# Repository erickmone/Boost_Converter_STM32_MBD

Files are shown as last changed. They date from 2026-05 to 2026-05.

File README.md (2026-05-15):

# Boost Converter for Model-Based Design and Embedded Control

This repository contains the hardware, simulation, modeling, and embedded-control resources developed for a **DC-DC boost converter**. The project is intended as a complete workflow for power electronics experimentation, including schematic design, PCB layout, analytical modeling, simulation, communication tests, and model-based design validation using MATLAB/Simulink.

The converter is designed as a boost-type power stage with an input voltage range from **12 V to 24 V**, a nominal output voltage of **42 V**, and a maximum output current of **5 A**. The general architecture includes the power converter, auxiliary power supply, MOSFET gate driver stage, voltage and current sensing adaptation circuits, and a microcontroller-based digital control platform operating with a PWM frequency of **500 kHz**. The block diagram included in this repository summarizes the complete system-level structure, including the power stage, sensing interface, driver, ADC acquisition, and auxiliary supply paths. :contentReference[oaicite:0]{index=0}

## Repository Structure

The repository is organized into several folders according to the main development stages of the project:

- `HW/Boost_Converter_V1.0`  
  Contains the hardware design files for the boost converter, including the PCB layout developed in **Altium Designer**.

- `INKSCAPE`  
  Includes schematic illustrations, block diagrams, and graphical material prepared using **Inkscape**. These files are useful for documentation, presentations, and technical explanations of the converter architecture.

- `MAPLE`  
  Contains symbolic calculations and additional analytical developments performed in **Maple**. These files may include derivations of converter equations, transfer functions, or supporting mathematical expressions.

- `Modbus Poll`  
  Includes material related to communication tests using **Modbus**, mainly for validating data exchange between the converter control system and external monitoring tools.

- `Papers`  
  Contains selected references and technical papers related to boost converters, digital control, power electronics modeling, and model-based design methodologies.

- `Simulation`  
  Includes simulation resources used to validate the converter operation before or alongside hardware implementation.

- `LEDtest.slxc`  
  A basic Simulink test model used to validate the embedded workflow, deployment process, and microcontroller output behavior.

- `PWM_STM32_g431xx_Boost_Converter.slx`  
  Simulink model for PWM generation on the STM32G431 platform.

- `PWM_STM32_g431xx_Boost_Converter_ADC_...slx`  
  Simulink model focused on ADC acquisition tests for voltage and current measurements.

- `PWM_STM32_g431xx_Boost_Converter_Contr...slx`  
  Simulink model including the first digital control implementation, based on a PI controller.

- `Startup_Parameters.m`  
  MATLAB script containing initialization parameters used by the Simulink models.

- `Transfer_Functions_Boost_STM32.m`  
  MATLAB script for defining and analyzing boost converter transfer functions.

- `regiones_Boost_STM32.m`  
  MATLAB script associated with the analysis of control regions or stability-related computations.

## Project Overview

The main goal of this repository is to document and validate a complete development process for a digitally controlled boost converter. The workflow combines classical power electronics design, simulation-based validation, and embedded implementation through model-based design.

The project includes:

1. **Power stage design**  
   The converter is based on a boost topology designed for low-voltage DC input and a regulated higher-voltage DC output.

2. **Hardware development**  
   The PCB layout is developed in Altium Designer and includes the main power stage, sensing circuits, auxiliary power supply, and interface connections for digital control.

3. **Graphical documentation**  
   System diagrams and converter illustrations are prepared in Inkscape to support documentation, presentations, and educational material.

4. **Analytical modeling**  
   Symbolic and numerical calculations are included to support the derivation of the dynamic model, transfer functions, and control-oriented representations.

5. **Model-based design validation**  
   Several Simulink models are included to validate the embedded workflow step by step, starting from basic LED tests, then PWM generation, ADC acquisition, and finally digital PI control.

6. **Communication testing**  
   Modbus-related files are included for communication and monitoring experiments.

7. **Experimental visualization**  
   Additional PDF diagrams and visual resources are included to document the overall architecture, signal flow, and system-level integration.

## Hardware Specifications

The preliminary system specifications are:

| Parameter | Value |
|---|---:|
| Converter topology | Boost converter |
| Input voltage range | 12 V – 24 V |
| Maximum input current | 10 A |
| Output voltage | 42 V |
| Maximum output current | 5 A |
| PWM frequency | 500 kHz |
| Control platform | STM32G431-based microcontroller |
| Control approach | Digital PI control |
| Sensing | Voltage and current ADC acquisition |
| Auxiliary supplies | 5 V and 3.3 V |

## Model-Based Design Tests

This repository includes several Simulink-based tests for embedded validation. The workflow follows a progressive strategy:

1. **LED test**  
   Basic deployment and GPIO validation on the target microcontroller.

2. **PWM generation test**  
   Validation of high-frequency PWM generation for the MOSFET gate driver.

3. **ADC acquisition test**  
   Verification of voltage and current measurement channels.

4. **Digital PI controller test**  
   First closed-loop control implementation for the boost converter.

This progressive validation approach makes it easier to isolate hardware, firmware, and control-design issues before integrating the complete system.

## Visualization and Documentation

The repository also includes visual documentation files, such as block diagrams and schematic illustrations. These resources are intended to make the project easier to understand from a system-level perspective.

The general block diagram describes the interaction between:

- DC input power supply,
- boost power stage,
- MOSFET gate driver,
- microcontroller,
- ADC sensing and adaptation circuits,
- auxiliary 5 V and 3.3 V power supplies,
- output load.

These visual elements are especially useful for tutorials, reports, presentations, and future educational material.

## Videos

A future section will include videos showing experimental tests and development progress. Possible video topics include:

- Hardware overview of the boost converter PCB.
- PWM generation test using STM32 and Simulink.
- ADC acquisition for voltage and current sensing.
- First open-loop experiments.
- Digital PI controller validation.
- Modbus-based monitoring.
- Complete system demonstration.

Video links will be added here as the tests are documented.

## Notes

Some files and scripts may include additional packages, preliminary variables, or unused sections. These elements are intentionally preserved because the repository is expected to evolve toward more advanced control-oriented tasks, including transfer-function analysis, stability-region computation, and digital controller validation.

Most of the material is currently organized as a development repository. Future updates may include a complete tutorial, additional experimental results, and a more detailed explanation of the mathematical modeling and embedded implementation.

## Author

Developed by:

- Michael Hernández & [@erickmone](https://www.github.com/erickmone)

You can also follow my academic work here:

- [Google Scholar](https://scholar.google.com/citations?hl=es&user=TdECTdoAAAAJ)

## Acknowledgments

This project is part of an ongoing effort to develop, validate, and document power electronics converters using simulation, hardware design, and model-based embedded control tools.

Special emphasis is placed on reproducible workflows for power electronics education and research, combining tools such as:

- MATLAB/Simulink,
- STM32 embedded targets,
- Altium Designer,
- Maple,
- Inkscape,
- Modbus-based communication tools.

---

NopaLabs Logo

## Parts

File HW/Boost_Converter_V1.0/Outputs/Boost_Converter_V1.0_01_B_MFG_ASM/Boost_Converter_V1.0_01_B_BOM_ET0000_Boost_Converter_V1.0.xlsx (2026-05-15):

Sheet: Part List Report
 | BILL OF MATERIAL |  |  | ET0000
 |  |  |  | Boost_Converter_V1.0
 | PCB Reference: |  |  | Boost_Converter_V1.0
 | Assembly Reference: |  | ASM number : | Boost_Converter_V1.0
 |  |  | ASM Variant : | 01
 |  |  | ASM Index (Lot) : | B
 | Report Date: |  |  | 07/11/2025 | 07:44
# | Designator | Comment | Description | Footprint | manufacturer | Part Number | Supplier 1 | Supplier Part Number 1 | Code Achat | Quantity
1 | C1 | 270pF | CAP CER 270PF 100V C0G/NP0 0603 | CAP 0603_1608 | KEMET | C0603C271J1GACAUTO |  |  |  | 1
2 | C2, C4, C5, C6, C7 | 10 µF | CAP CER 10UF 100V X7S 1210 | MURATA - GRM32E | Murata Electronics | GRM32EC72A106KE05L | DigiKey | 490-16266-1-ND |  | 5
3 | C3, C19, C20 | 100nF@100V | CAP CER 0.1UF 100V X8R 0603 | CAP 0603_1608 | Murata Electronics | GCG188R92A104KA03D | DigiKey | 490-18197-1-ND |  | 3
4 | C8, C9, C10, C11, C12, C13, C14, C15, C18, C21 | 0.1 µF | CAP CER 0.1UF 16V X7R 0603 | CAP 0603_1608 | Yageo | CS0603KRX7R7BB104 | DigiKey | 311-3560-1-ND |  | 10
5 | C16, C17, C22 | 220nF | CAP CER 0603 220NF 16V X7R 10% | CAP 0603_1608 | KEMET | C0603C224K4RECAUTO |  |  |  | 3
6 | D1 | Red | LED RED SMD | LED 0603_1608 RED | Citizen | CL-195HR-CD-T | DigiKey | 1642-1492-1-ND |  | 1
7 | D2 | White | LED WHITE SMD | LED 0603_1608 | Citizen | CL-198N-WS-D-T | DigiKey | 1642-1495-1-ND |  | 1
8 | D3 | V40PW10C-M3/I | Rectifier Diode Schottky 100V 40A 3-Pin(2+Tab) Slim DPAK T/R | TO-252 | Vishay | V40PW10C | Mouser | 78-V40PW10C-M3/I |  | 1
9 | L1 | 15µH@14A | FIXED IND 15UH 14A 9 MOHM SMD | WURTH WE-HCI 1890 | Würth Elektronik | 74435571500 |  |  |  | 1
10 | Q1 | IPD30N12S3L-31 | Mosfet Single, 30A, 120V, 57W, To-252-3 Rohs Compliant: Yes |Infineon | TO-252 | Infineon | IPD30N06S4L-23 | Mouser | 726-IPD30N12S3L31AT |  | 1
11 | R1 | 2R21 | RES 2.21 OHM 1% 1/8W 0603 | RES 0603_1608 | KOA Speer Electronics, Inc. | RK73H1JTTD2R21F |  |  |  | 1
12 | R2, R3 | 22R | RES SMD 22 OHM 1% 1/10W 0603 | RES 0603_1608 | Panasonic Electronic Components | ERJ-3EKF22R0V | DigiKey | P22.0HCT-ND |  | 2
13 | R4, R9, R10, R11, R12, R13, R14, R15, R16 | 10k | RES 10K OHM 0.1% 1/10W 0603 | RES 0603_1608 | Vishay Dale | TNPW060310K0BETA |  |  |  | 9
14 | R5 | 10R | RES SMD 10 OHM 1% 1/4W 0603 | RES 0603_1608 | Rohm Semiconductor | ESR03EZPF10R0 | DigiKey | RHM10.0ADCT-ND |  | 1
15 | R6, R7, R8 | 300K | RES SMD 300K OHM 1% 1/3W 0603 | RES 0603_1608 | Vishay Dale | CRCW0603300KFKEAHP | DigiKey | 541-CRCW0603300KFKEAHPCT-ND |  | 3
16 | Rcs1, Rcs2 | 0R01 | RES 0.01 OHM 1% 3W 2512 | RES 2512_6432 | Vishay Dale | WSLP2512R0100FEA |  |  |  | 2
17 | U1 | STM32G431KBT6 | STMICROELECTRONICS STM32G431KBT6 MCU ARM, STM32 Family STM32G4 Series Microcontrollers, ARM Cortex-M4F, 32 bits, 170 MHz, 128 KB Fabricant | STM-LQFP32_N | STM | STM32G431KBT6 | Farnell | 3132405 |  | 1
18 | U2 | IX4310T | 2 Ampere High Speed Low-Side MOSFET Driver | SOT-23-5 | IXYS | IX4310T |  |  |  | 1
19 | U3 | AP7381-50Y-13 | IC REG LINEAR 5V 150MA SOT89 | DIODES INC SOT-89 | Diodes Incorporated | AP7381-50Y-13 |  |  |  | 1
20 | U4, U6 | INA296B1IDDFR | 10V/V "-5-V TO 110-V, BIDIRECTIONAL, 1." Current Sense Amplifier 1 Circuit Single-Ended 8-VSSOP | SOT65P280X110-8N | Texas Instruments | INA296B1IDDFR | Mouser | 595-INA296B1IDDFR |  | 2
21 | U5 | AP7381-33Y-13 | IC REG LINEAR 3.3V 150MA SOT89 | DIODES INC SOT-89 | Diodes Incorporated | AP7381-33Y-13 |  |  |  | 1
 |  |  |  |  |  |  |  |  |  | 51
Approved |  |  |  |  | Notes
 |  |  |  |  | NC/DNC = Non Câblé
 |  |  |  |  | Affichage : Verifier l'alignement automatique des lignes sous peine d'occultation de certaines références
 |  |  |  |  | Codes Achat:
 |  |  |  |  |  | A = Appro sur caratéristiques
 |  |  |  |  |  | B = Référence Fabricant à respecter

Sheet: Project Information
Project Full Path | C:\Mike\Mike\Boost_Converter\Boost\HW\Boost_Converter_V1.0\Boost_Converter_V1.0.PrjPcb
Project Filename | Boost_Converter_V1.0.PrjPcb
Variant Name | 01
Data-Source Filename | Boost_Converter_V1.0.PrjPcb
Data-Source Full Path | C:\Mike\Mike\Boost_Converter\Boost\HW\Boost_Converter_V1.0\Boost_Converter_V1.0.PrjPcb
Title | ET0000
Total Quantity | 51
Report Time | 07:44
Report Date | 07/11/2025
Report Date & Tine | 07/11/2025 07:44
Output Name | Bill of Materials
Output Type | BomReport
Output Generator Name | BOM
Output Generator Description | TemplateBOM_1

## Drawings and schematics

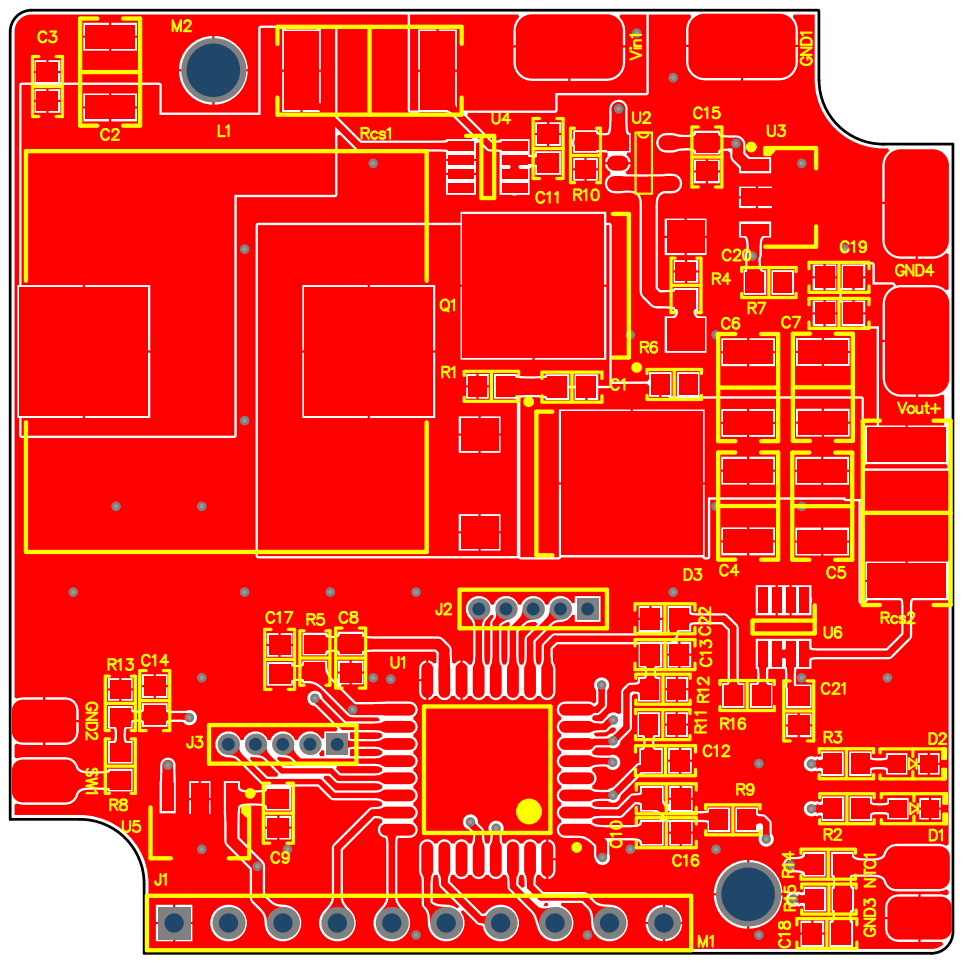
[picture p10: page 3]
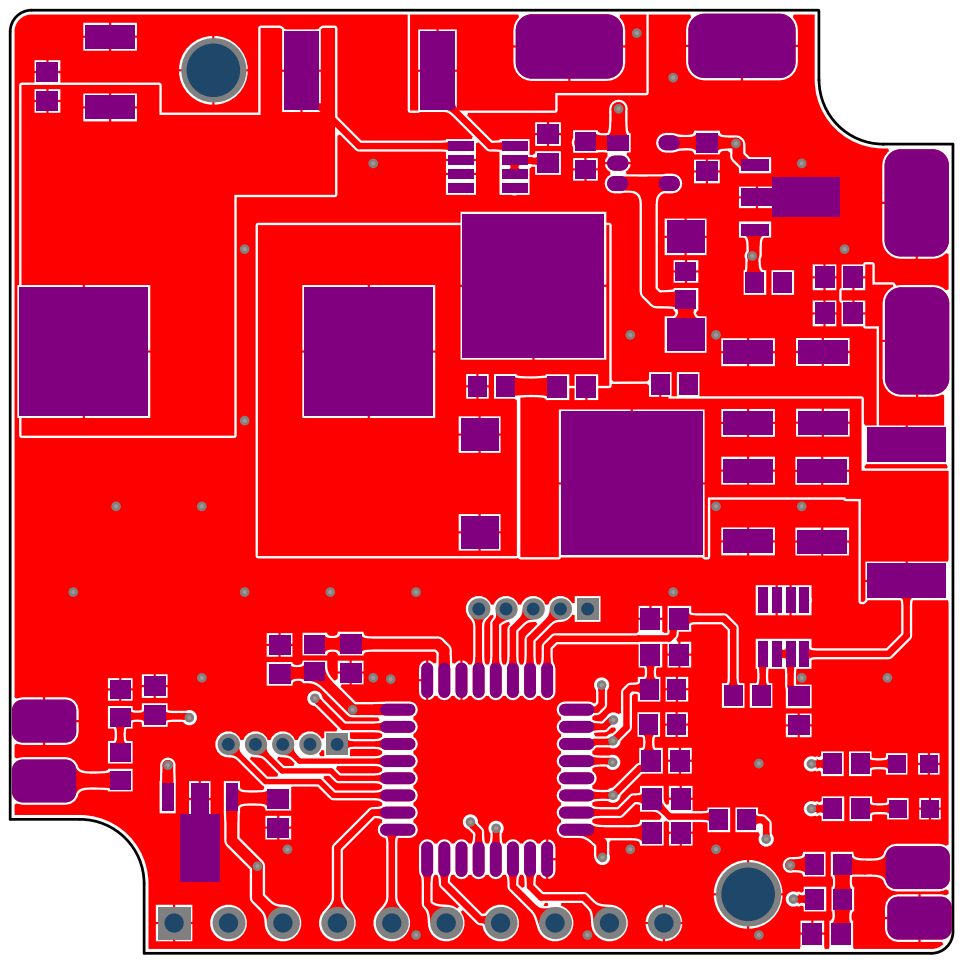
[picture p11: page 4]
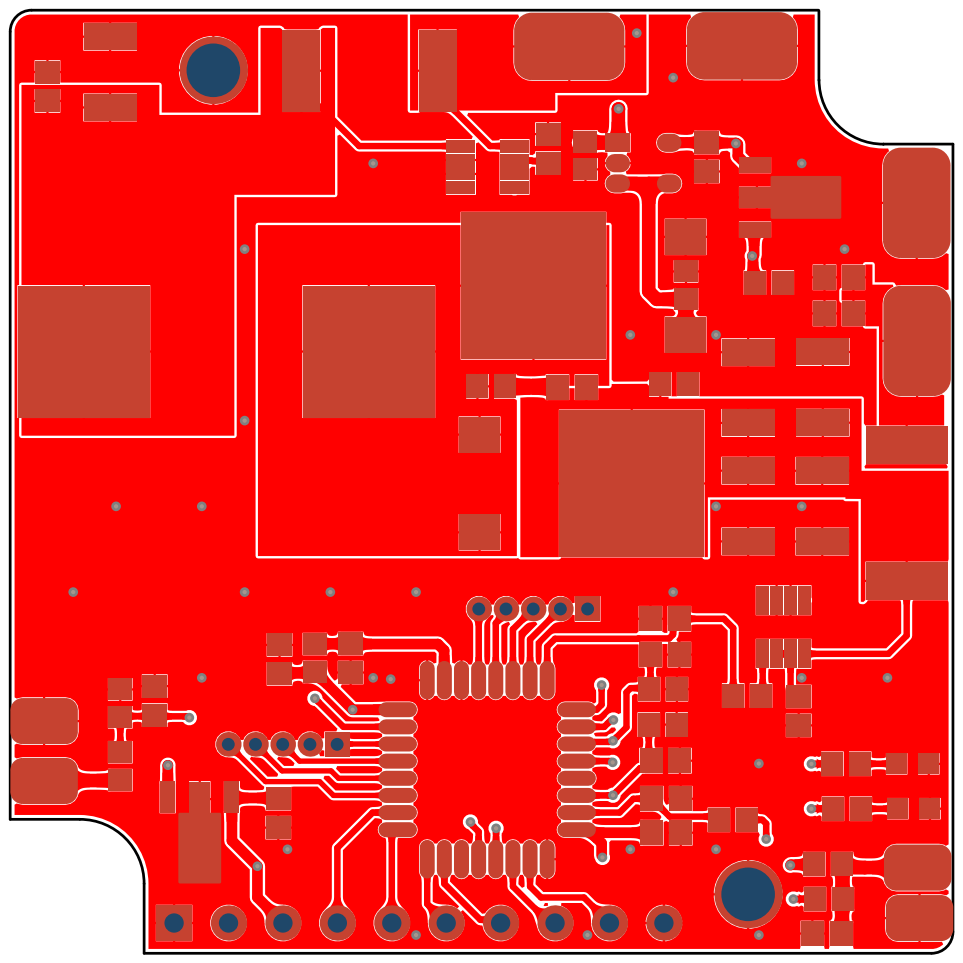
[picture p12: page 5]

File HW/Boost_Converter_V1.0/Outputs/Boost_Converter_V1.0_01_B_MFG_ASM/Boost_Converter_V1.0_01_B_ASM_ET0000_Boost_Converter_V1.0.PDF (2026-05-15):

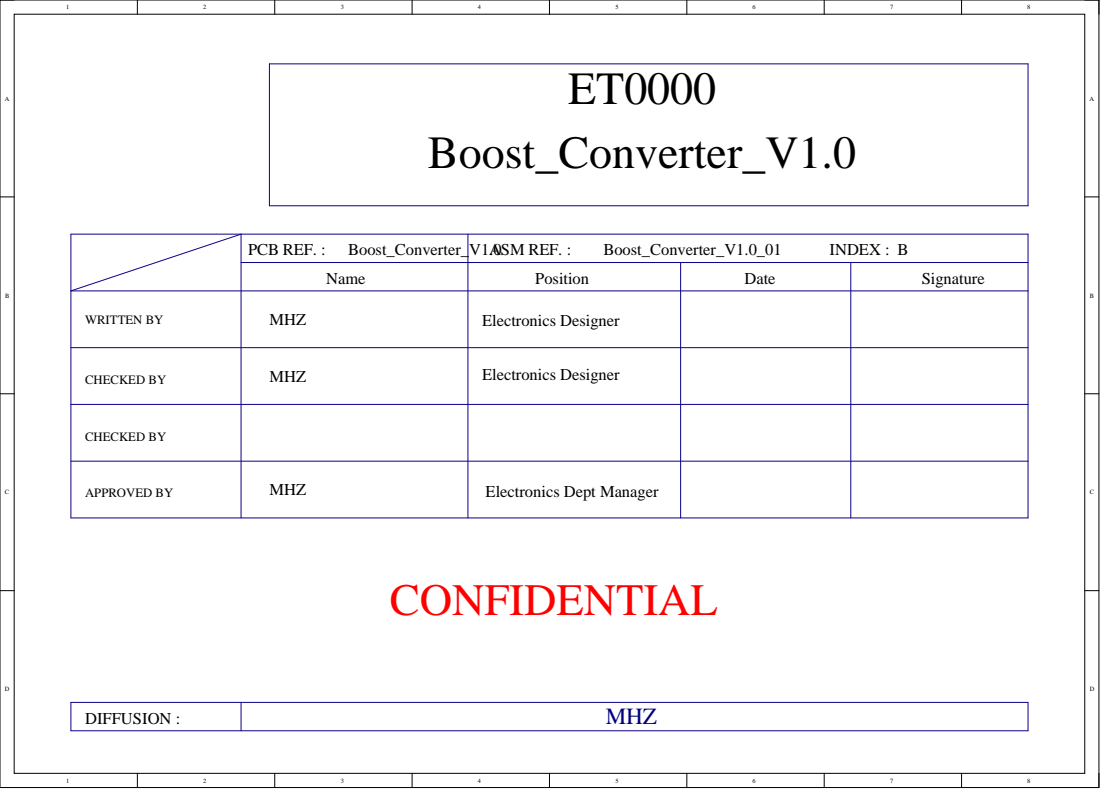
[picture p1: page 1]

PCB REF. : Boost_Converter_V1.0 | ASM REF. : Boost_Converter_V1.0_01 INDEX : B

Name | Position | Date | Signature

WRITTEN BY | MHZ | Electronics Designer

CHECKED BY | MHZ | Electronics Designer

CHECKED BY

APPROVED BY | MHZ | Electronics Dept Manager

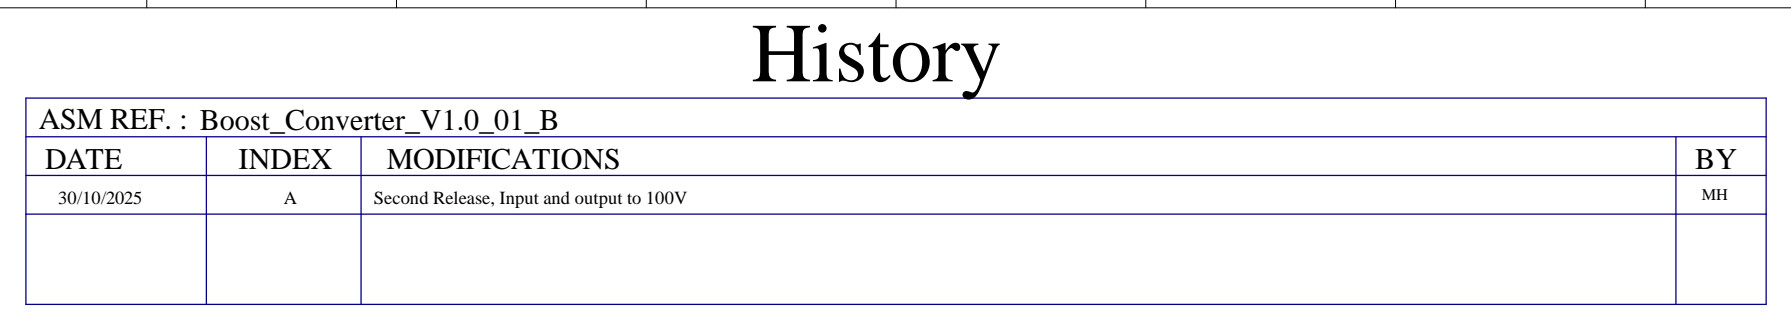
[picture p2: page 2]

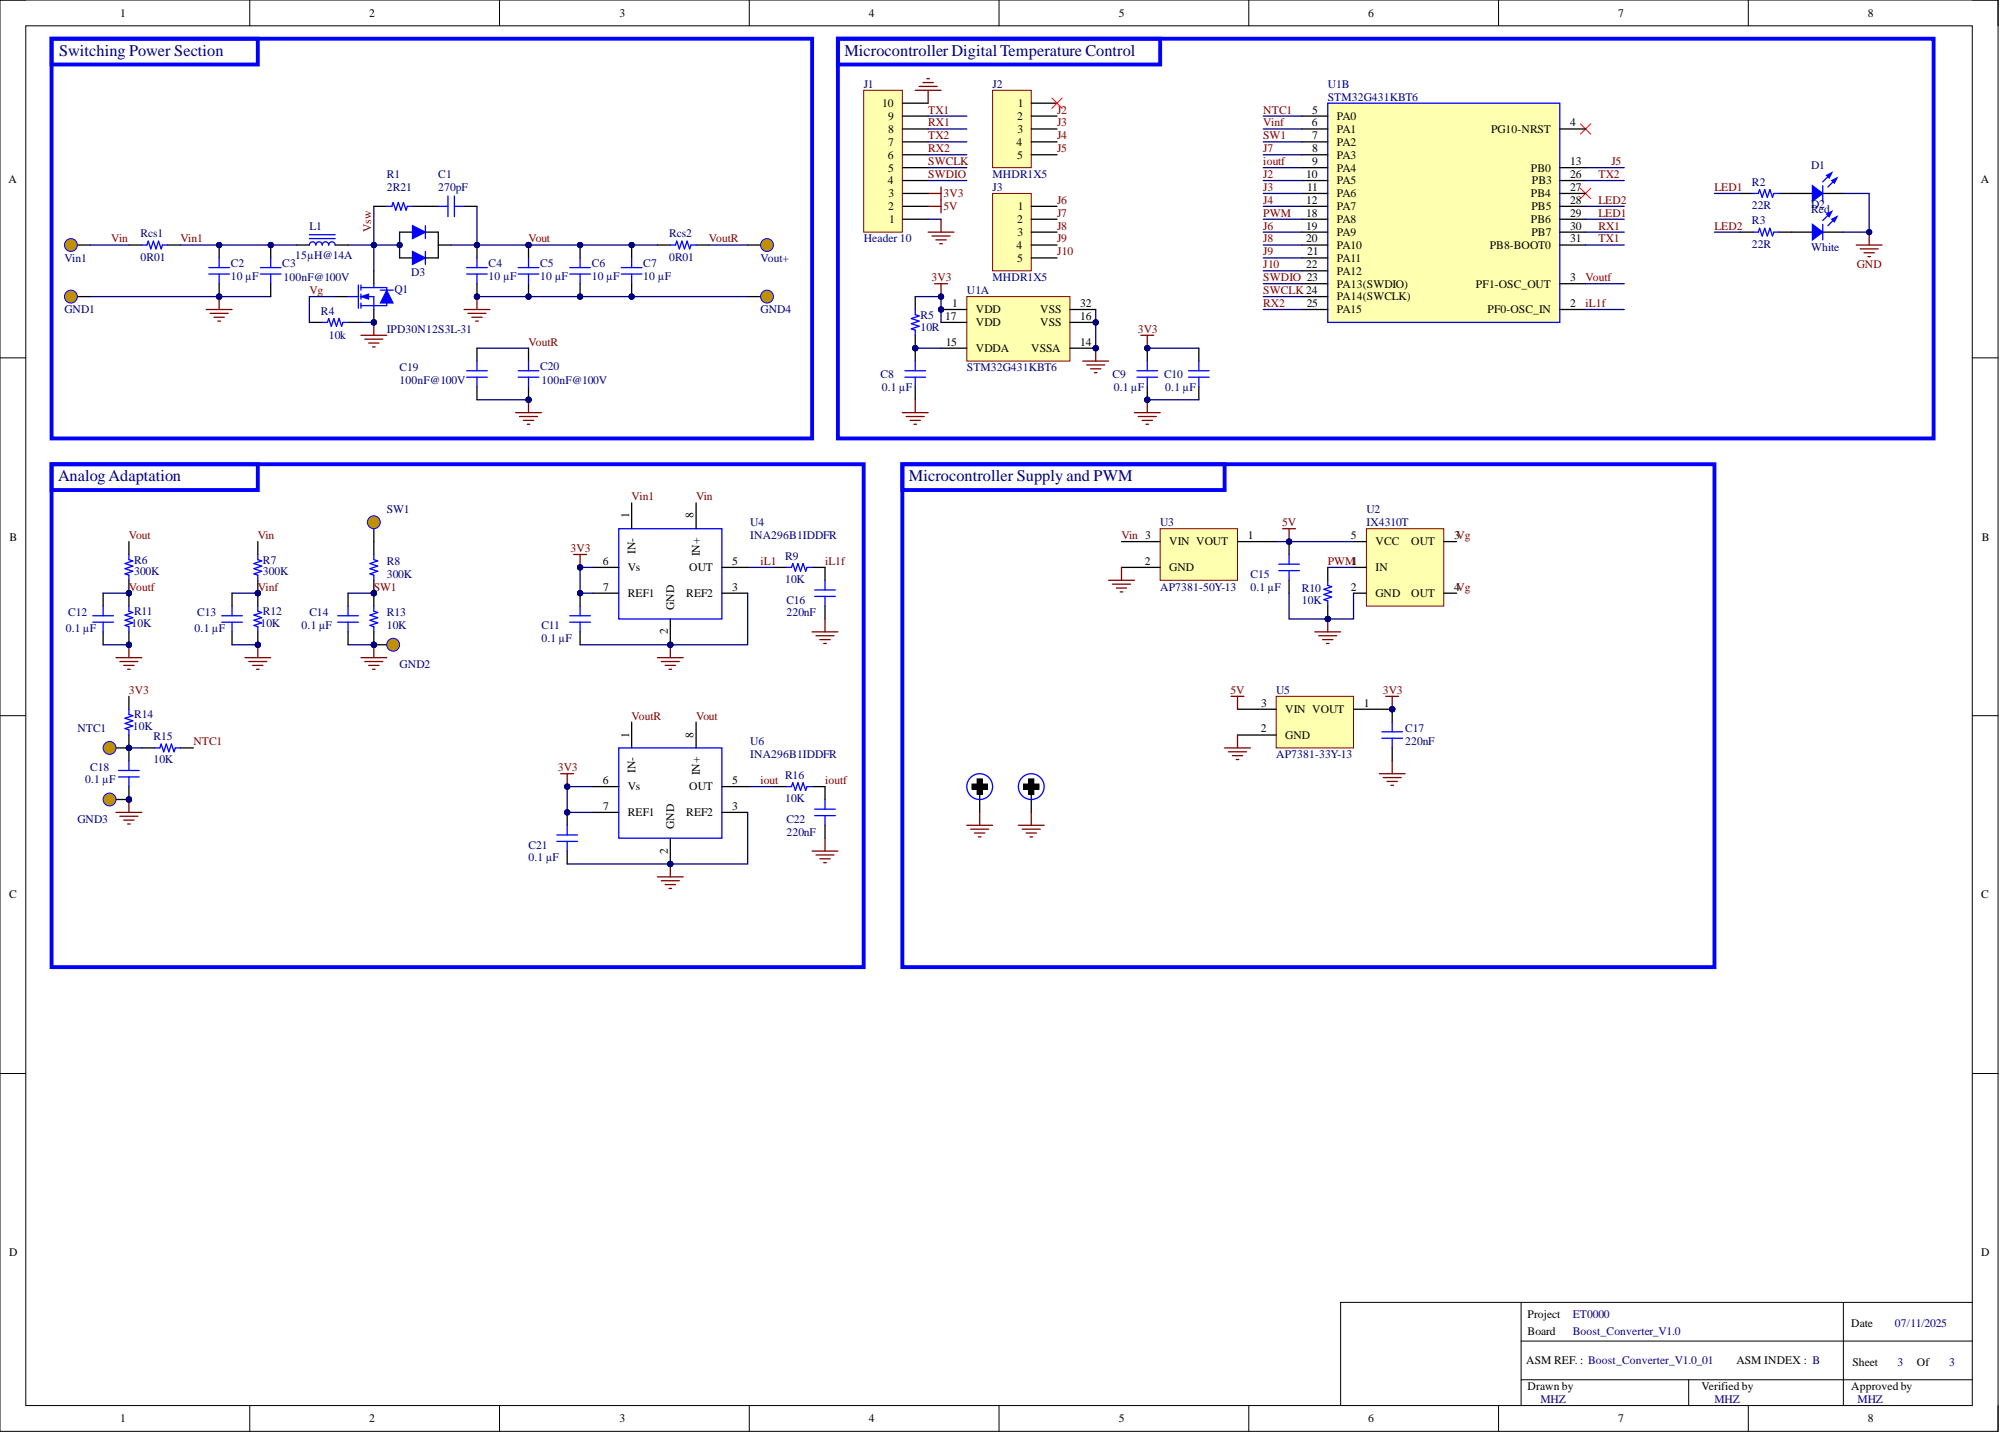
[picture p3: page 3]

ler Supply and PWM

BILL OF MATERIAL | ET0000

## Boost_Converter_V1.0

PCB Reference: | Boost_Converter_V1.0
Assembly Reference: | ASM number : Boost_Converter_V1.0
| ASM Variant : 01
| ASM Index (Lot) : B
Report Date: | 07/11/2025 | 07:42
# | Designator | Comment | Description | Footprint | manufacturer | Part Number | Supplier 1 | Supplier Part Number 1 | Code Achat | Quantity

1 | C1 | 270pF | CAP CER 270PF 100V C0G/NP0 0603 | CAP 0603_1608 | KEMET | C0603C271J1GACAUTO | | | | 1
2 | C2, C4, C5, C6, C7 | 10 µF | CAP CER 10UF 100V X7S 1210 | MURATA - GRM32E | Murata Electronics | GRM32EC72A106KE05L | DigiKey | 490-16266-1-ND | | 5
3 | C3, C19, C20 | 100nF@100V | CAP CER 0.1UF 100V X8R 0603 | CAP 0603_1608 | Murata Electronics | GCG188R92A104KA03D | DigiKey | 490-18197-1-ND | | 3
4 | C8, C9, C10, C11, C12, C13, C14, C15, C18, C21 | 0.1 µF | CAP CER 0.1UF 16V X7R 0603 | CAP 0603_1608 | Yageo | CS0603KRX7R7BB104 | DigiKey | 311-3560-1-ND | | 10
5 | C16, C17, C22 | 220nF | CAP CER 0603 220NF 16V X7R 10% | CAP 0603_1608 | KEMET | C0603C224K4RECAUTO | | | | 3
6 | D1 | Red | LED RED SMD | LED 0603_1608 RED | Citizen | CL-195HR-CD-T | DigiKey | 1642-1492-1-ND | | 1
7 | D2 | White | LED WHITE SMD | LED 0603_1608 | Citizen | CL-198N-WS-D-T | DigiKey | 1642-1495-1-ND | | 1
8 | D3 | V40PW10C-M3/I | Rectifier Diode Schottky 100V 40A 3-Pin(2+Tab) Slim DPAK T/R | TO-252 | Vishay | V40PW10C | Mouser | 78-V40PW10C-M3/I | | 1
9 | L1 | 15µH@14A | FIXED IND 15UH 14A 9 MOHM SMD | WURTH WE-HCI 1890 | Würth Elektronik | 74435571500 | | | | 1
10 | Q1 | IPD30N12S3L-31 | Mosfet Single, 30A, 120V, 57W, To-252-3 Rohs Compliant: Yes |Infineon | TO-252 | Infineon | IPD30N06S4L-23 | Mouser | 726-IPD30N12S3L31AT | | 1
11 | R1 | 2R21 | RES 2.21 OHM 1% 1/8W 0603 | RES 0603_1608 | KOA Speer Electronics, Inc. | RK73H1JTTD2R21F | | | | 1
12 | R2, R3 | 22R | RES SMD 22 OHM 1% 1/10W 0603 | RES 0603_1608 | Panasonic Electronic Components | ERJ-3EKF22R0V | DigiKey | P22.0HCT-ND | | 2
13 | R4, R9, R10, R11, R12, R13, R14, R15, R16 | 10k | RES 10K OHM 0.1% 1/10W 0603 | RES 0603_1608 | Vishay Dale | TNPW060310K0BETA | | | | 9
14 | R5 | 10R | RES SMD 10 OHM 1% 1/4W 0603 | RES 0603_1608 | Rohm Semiconductor | ESR03EZPF10R0 | DigiKey | RHM10.0ADCT-ND | | 1
15 | R6, R7, R8 | 300K | RES SMD 300K OHM 1% 1/3W 0603 | RES 0603_1608 | Vishay Dale | CRCW0603300KFKEAHP | DigiKey | 541-CRCW0603300KFKEAHPCT-ND | | 3
16 | Rcs1, Rcs2 | 0R01 | RES 0.01 OHM 1% 3W 2512 | RES 2512_6432 | Vishay Dale | WSLP2512R0100FEA | | | | 2
17 | U1 | STM32G431KBT6 | STMICROELECTRONICS STM32G431KBT6 MCU ARM, STM32 Family STM32G4 Series Microcontrollers, ARM Cortex-M4F, 32 bits, 170 MHz, 128 KB Fabricant | STM-LQFP32_N | STM | STM32G431KBT6 | Farnell | 3132405 | | 1
18 | U2 | IX4310T | 2 Ampere High Speed Low-Side MOSFET Driver | SOT-23-5 | IXYS | IX4310T | | | | 1
19 | U3 | AP7381-50Y-13 | IC REG LINEAR 5V 150MA SOT89 | DIODES INC SOT-89 | Diodes Incorporated | AP7381-50Y-13 | | | | 1
20 | U4, U6 | INA296B1IDDFR | 10V/V "-5-V TO 110-V, BIDIRECTIONAL, 1." Current Sense Amplifier 1 Circuit Single-Ended 8-VSSOP | SOT65P280X110-8N | Texas Instruments | INA296B1IDDFR | Mouser | 595-INA296B1IDDFR | | 2
21 | U5 | AP7381-33Y-13 | IC REG LINEAR 3.3V 150MA SOT89 | DIODES INC SOT-89 | Diodes Incorporated | AP7381-33Y-13 | | | | 1
51
Approved | | | | | Notes NC/DNC = Non Câblé Affichage : Verifier l'alignement automatique des lignes sous peine d'occultation de certaines références Codes Achat: A = Appro sur caratéristiques B = Référence Fabricant à respecter

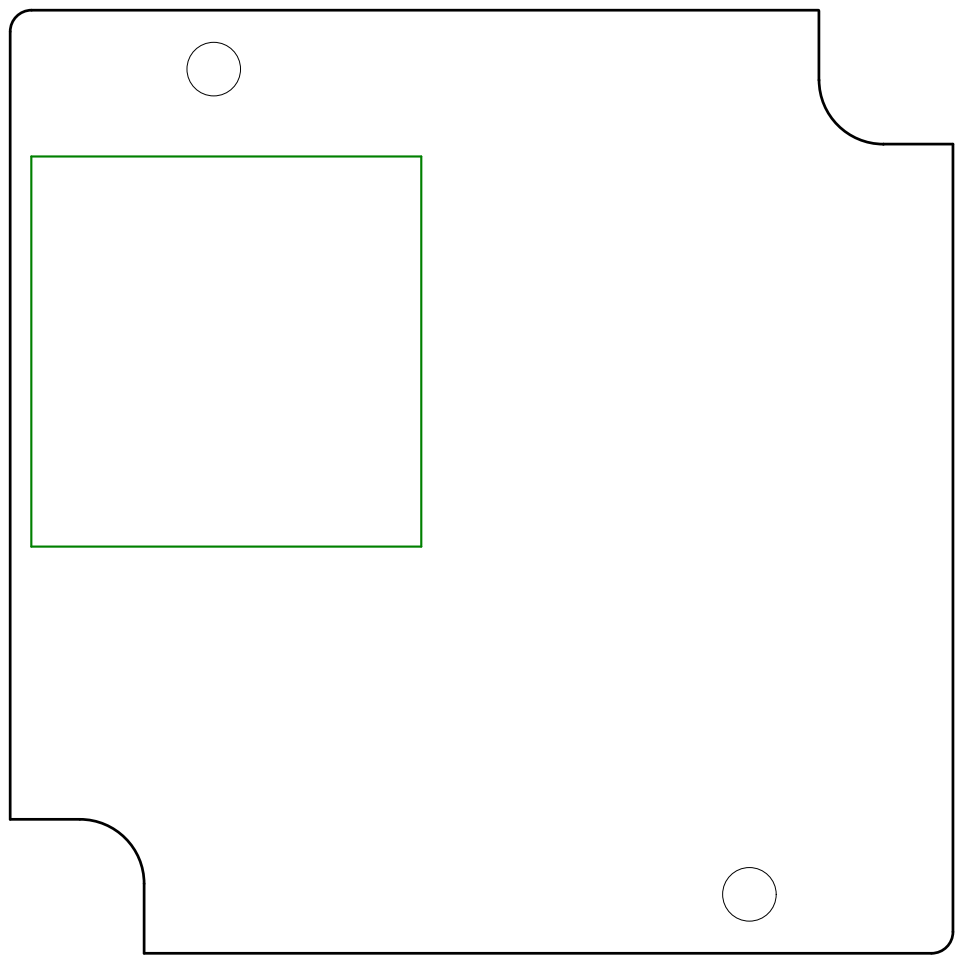
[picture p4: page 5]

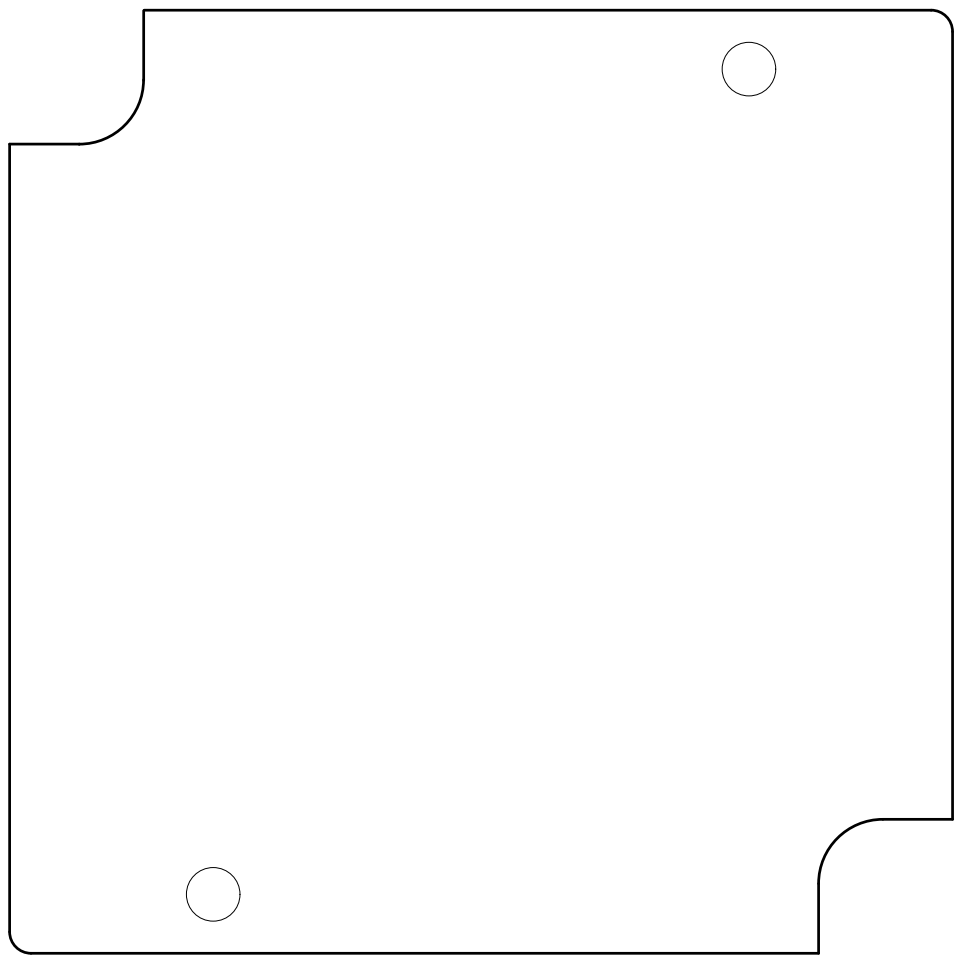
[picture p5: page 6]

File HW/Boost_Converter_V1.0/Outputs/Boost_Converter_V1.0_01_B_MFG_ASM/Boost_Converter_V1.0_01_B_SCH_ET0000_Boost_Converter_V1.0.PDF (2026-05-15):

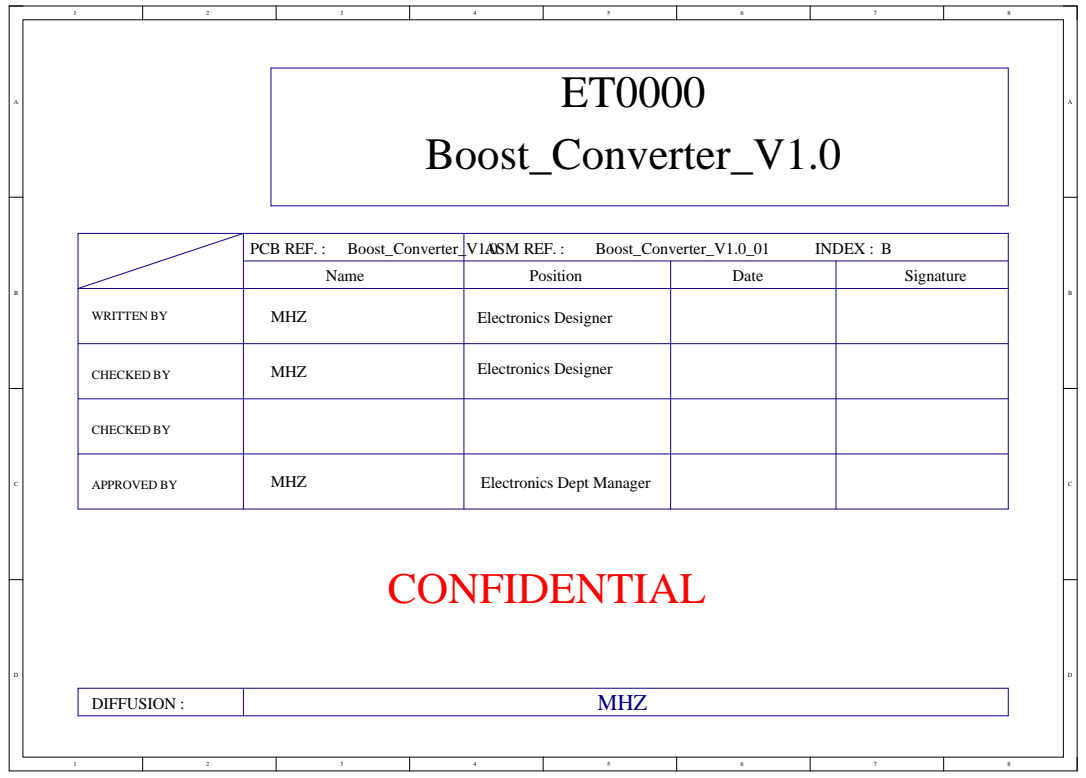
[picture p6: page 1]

PCB REF. : Boost_Converter_V1.0 | ASM REF. : Boost_Converter_V1.0_01 INDEX : B

Name | Position | Date | Signature

WRITTEN BY | MHZ | Electronics Designer

CHECKED BY | MHZ | Electronics Designer

CHECKED BY

APPROVED BY | MHZ | Electronics Dept Manager

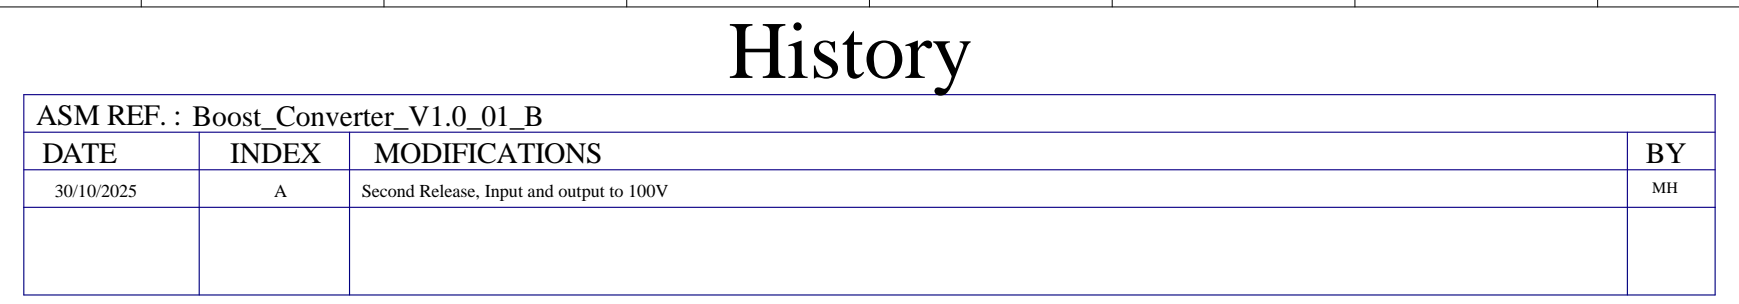
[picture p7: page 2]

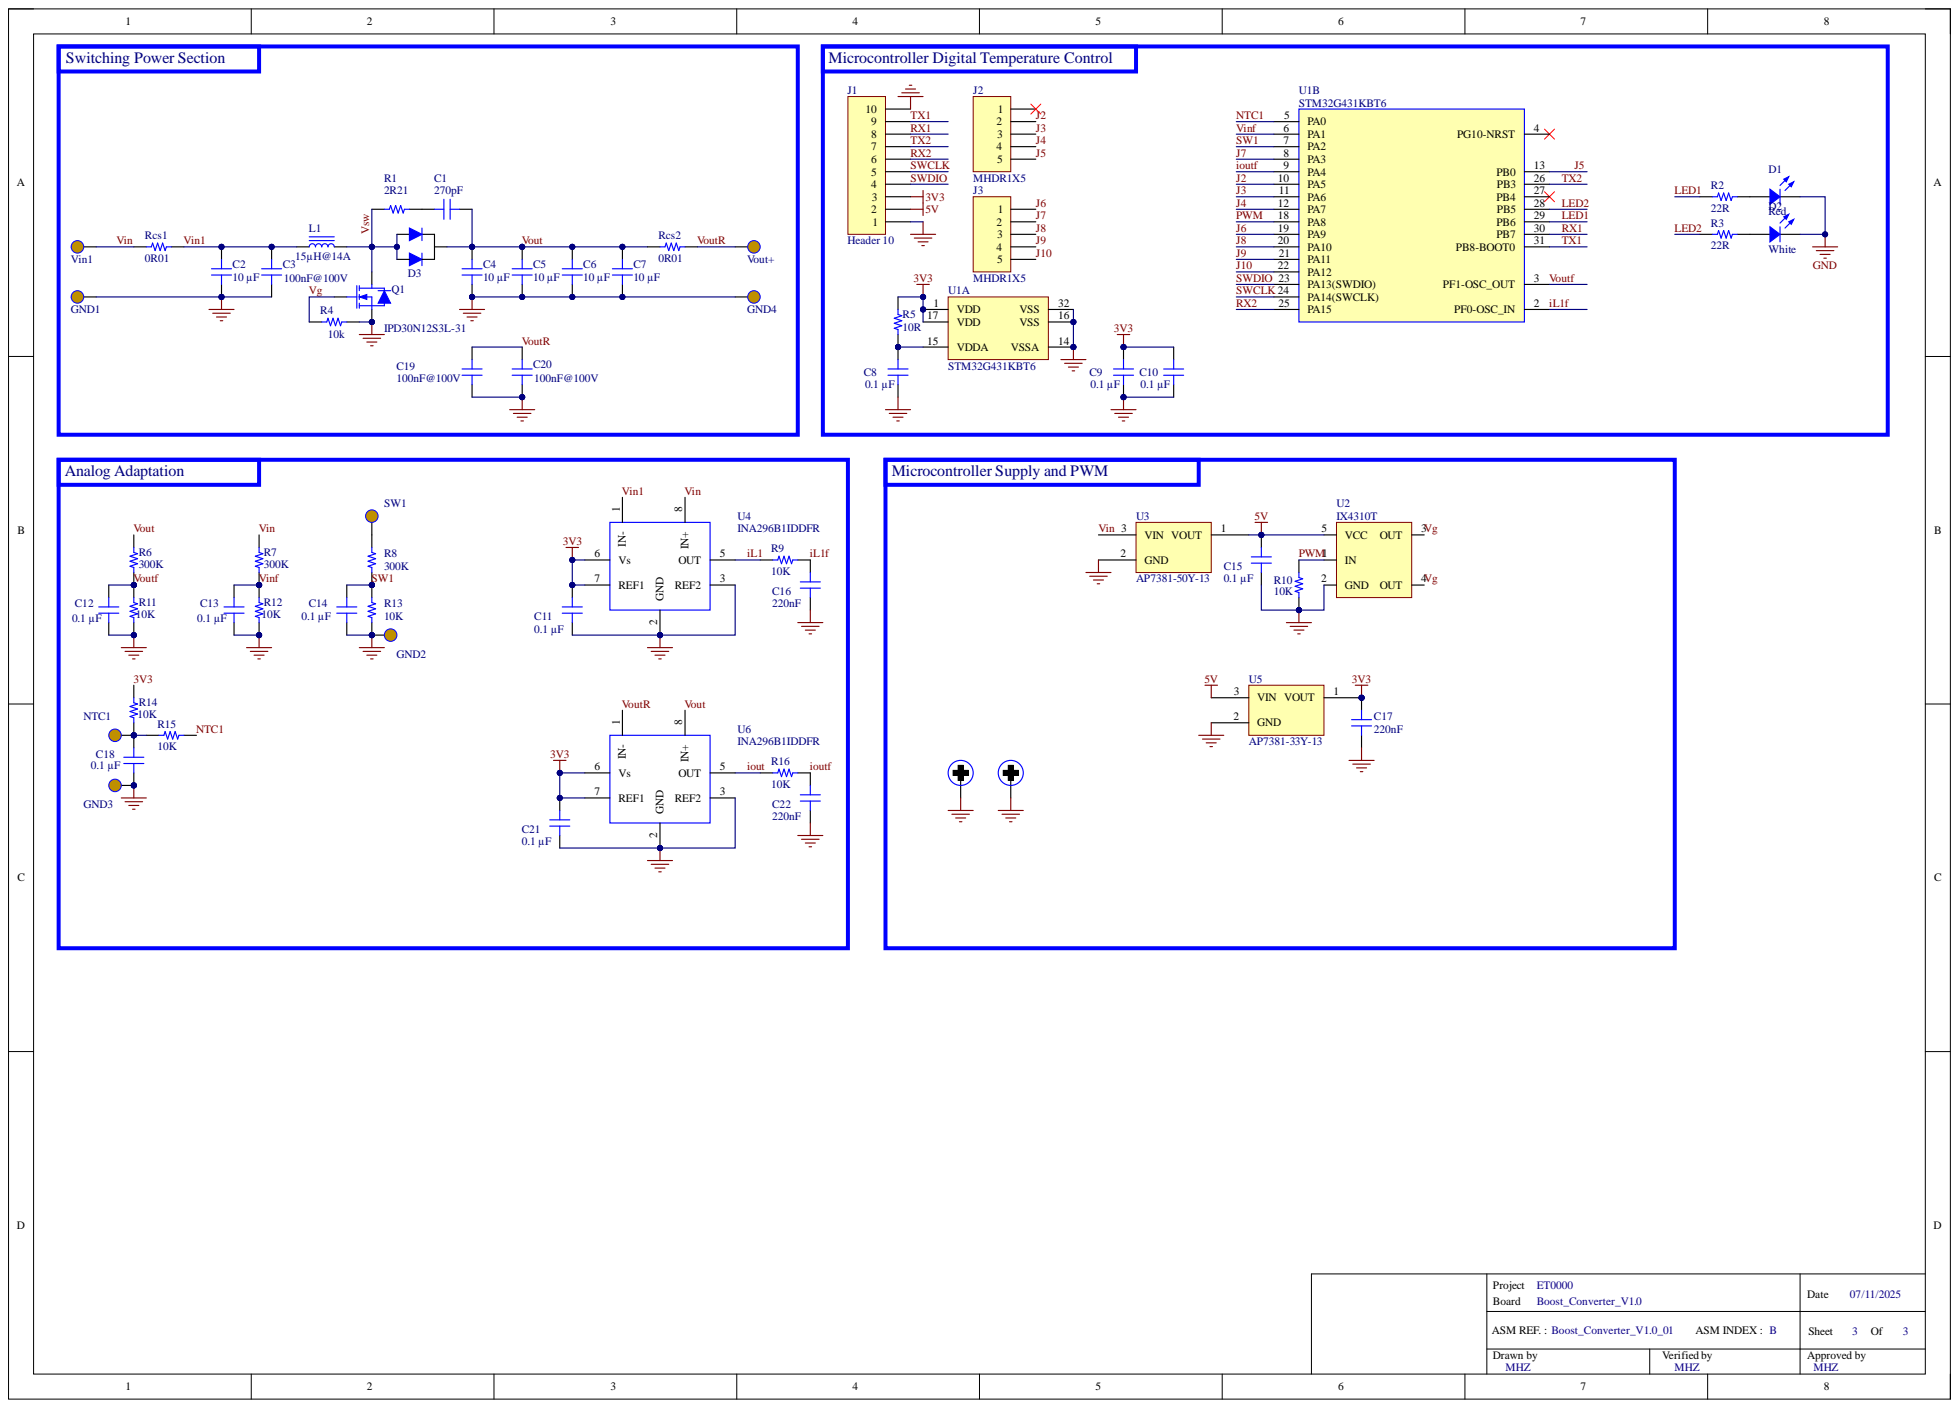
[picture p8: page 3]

Microcontroller Supply and PWM

BILL OF MATERIAL | ET0000

## Boost_Converter_V1.0

PCB Reference: | Boost_Converter_V1.0
Assembly Reference: | ASM number : Boost_Converter_V1.0
| ASM Variant : 01
| ASM Index (Lot) : B
Report Date: | 07/11/2025 | 07:41
# | Designator | Comment | Description | Footprint | manufacturer | Part Number | Supplier 1 | Supplier Part Number 1 | Code Achat | Quantity

1 | C1 | 270pF | CAP CER 270PF 100V C0G/NP0 0603 | CAP 0603_1608 | KEMET | C0603C271J1GACAUTO | | | | 1
2 | C2, C4, C5, C6, C7 | 10 µF | CAP CER 10UF 100V X7S 1210 | MURATA - GRM32E | Murata Electronics | GRM32EC72A106KE05L | DigiKey | 490-16266-1-ND | | 5
3 | C3, C19, C20 | 100nF@100V | CAP CER 0.1UF 100V X8R 0603 | CAP 0603_1608 | Murata Electronics | GCG188R92A104KA03D | DigiKey | 490-18197-1-ND | | 3
4 | C8, C9, C10, C11, C12, C13, C14, C15, C18, C21 | 0.1 µF | CAP CER 0.1UF 16V X7R 0603 | CAP 0603_1608 | Yageo | CS0603KRX7R7BB104 | DigiKey | 311-3560-1-ND | | 10
5 | C16, C17, C22 | 220nF | CAP CER 0603 220NF 16V X7R 10% | CAP 0603_1608 | KEMET | C0603C224K4RECAUTO | | | | 3
6 | D1 | Red | LED RED SMD | LED 0603_1608 RED | Citizen | CL-195HR-CD-T | DigiKey | 1642-1492-1-ND | | 1
7 | D2 | White | LED WHITE SMD | LED 0603_1608 | Citizen | CL-198N-WS-D-T | DigiKey | 1642-1495-1-ND | | 1
8 | D3 | V40PW10C-M3/I | Rectifier Diode Schottky 100V 40A 3-Pin(2+Tab) Slim DPAK T/R | TO-252 | Vishay | V40PW10C | Mouser | 78-V40PW10C-M3/I | | 1
9 | L1 | 15µH@14A | FIXED IND 15UH 14A 9 MOHM SMD | WURTH WE-HCI 1890 | Würth Elektronik | 74435571500 | | | | 1
10 | Q1 | IPD30N12S3L-31 | Mosfet Single, 30A, 120V, 57W, To-252-3 Rohs Compliant: Yes |Infineon | TO-252 | Infineon | IPD30N06S4L-23 | Mouser | 726-IPD30N12S3L31AT | | 1
11 | R1 | 2R21 | RES 2.21 OHM 1% 1/8W 0603 | RES 0603_1608 | KOA Speer Electronics, Inc. | RK73H1JTTD2R21F | | | | 1
12 | R2, R3 | 22R | RES SMD 22 OHM 1% 1/10W 0603 | RES 0603_1608 | Panasonic Electronic Components | ERJ-3EKF22R0V | DigiKey | P22.0HCT-ND | | 2
13 | R4, R9, R10, R11, R12, R13, R14, R15, R16 | 10k | RES 10K OHM 0.1% 1/10W 0603 | RES 0603_1608 | Vishay Dale | TNPW060310K0BETA | | | | 9
14 | R5 | 10R | RES SMD 10 OHM 1% 1/4W 0603 | RES 0603_1608 | Rohm Semiconductor | ESR03EZPF10R0 | DigiKey | RHM10.0ADCT-ND | | 1
15 | R6, R7, R8 | 300K | RES SMD 300K OHM 1% 1/3W 0603 | RES 0603_1608 | Vishay Dale | CRCW0603300KFKEAHP | DigiKey | 541-CRCW0603300KFKEAHPCT-ND | | 3
16 | Rcs1, Rcs2 | 0R01 | RES 0.01 OHM 1% 3W 2512 | RES 2512_6432 | Vishay Dale | WSLP2512R0100FEA | | | | 2
17 | U1 | STM32G431KBT6 | STMICROELECTRONICS STM32G431KBT6 MCU ARM, STM32 Family STM32G4 Series Microcontrollers, ARM Cortex-M4F, 32 bits, 170 MHz, 128 KB Fabricant | STM-LQFP32_N | STM | STM32G431KBT6 | Farnell | 3132405 | | 1
18 | U2 | IX4310T | 2 Ampere High Speed Low-Side MOSFET Driver | SOT-23-5 | IXYS | IX4310T | | | | 1
19 | U3 | AP7381-50Y-13 | IC REG LINEAR 5V 150MA SOT89 | DIODES INC SOT-89 | Diodes Incorporated | AP7381-50Y-13 | | | | 1
20 | U4, U6 | INA296B1IDDFR | 10V/V "-5-V TO 110-V, BIDIRECTIONAL, 1." Current Sense Amplifier 1 Circuit Single-Ended 8-VSSOP | SOT65P280X110-8N | Texas Instruments | INA296B1IDDFR | Mouser | 595-INA296B1IDDFR | | 2
21 | U5 | AP7381-33Y-13 | IC REG LINEAR 3.3V 150MA SOT89 | DIODES INC SOT-89 | Diodes Incorporated | AP7381-33Y-13 | | | | 1
51
Approved | | | | | Notes NC/DNC = Non Câblé Affichage : Verifier l'alignement automatique des lignes sous peine d'occultation de certaines références Codes Achat: A = Appro sur caratéristiques B = Référence Fabricant à respecter

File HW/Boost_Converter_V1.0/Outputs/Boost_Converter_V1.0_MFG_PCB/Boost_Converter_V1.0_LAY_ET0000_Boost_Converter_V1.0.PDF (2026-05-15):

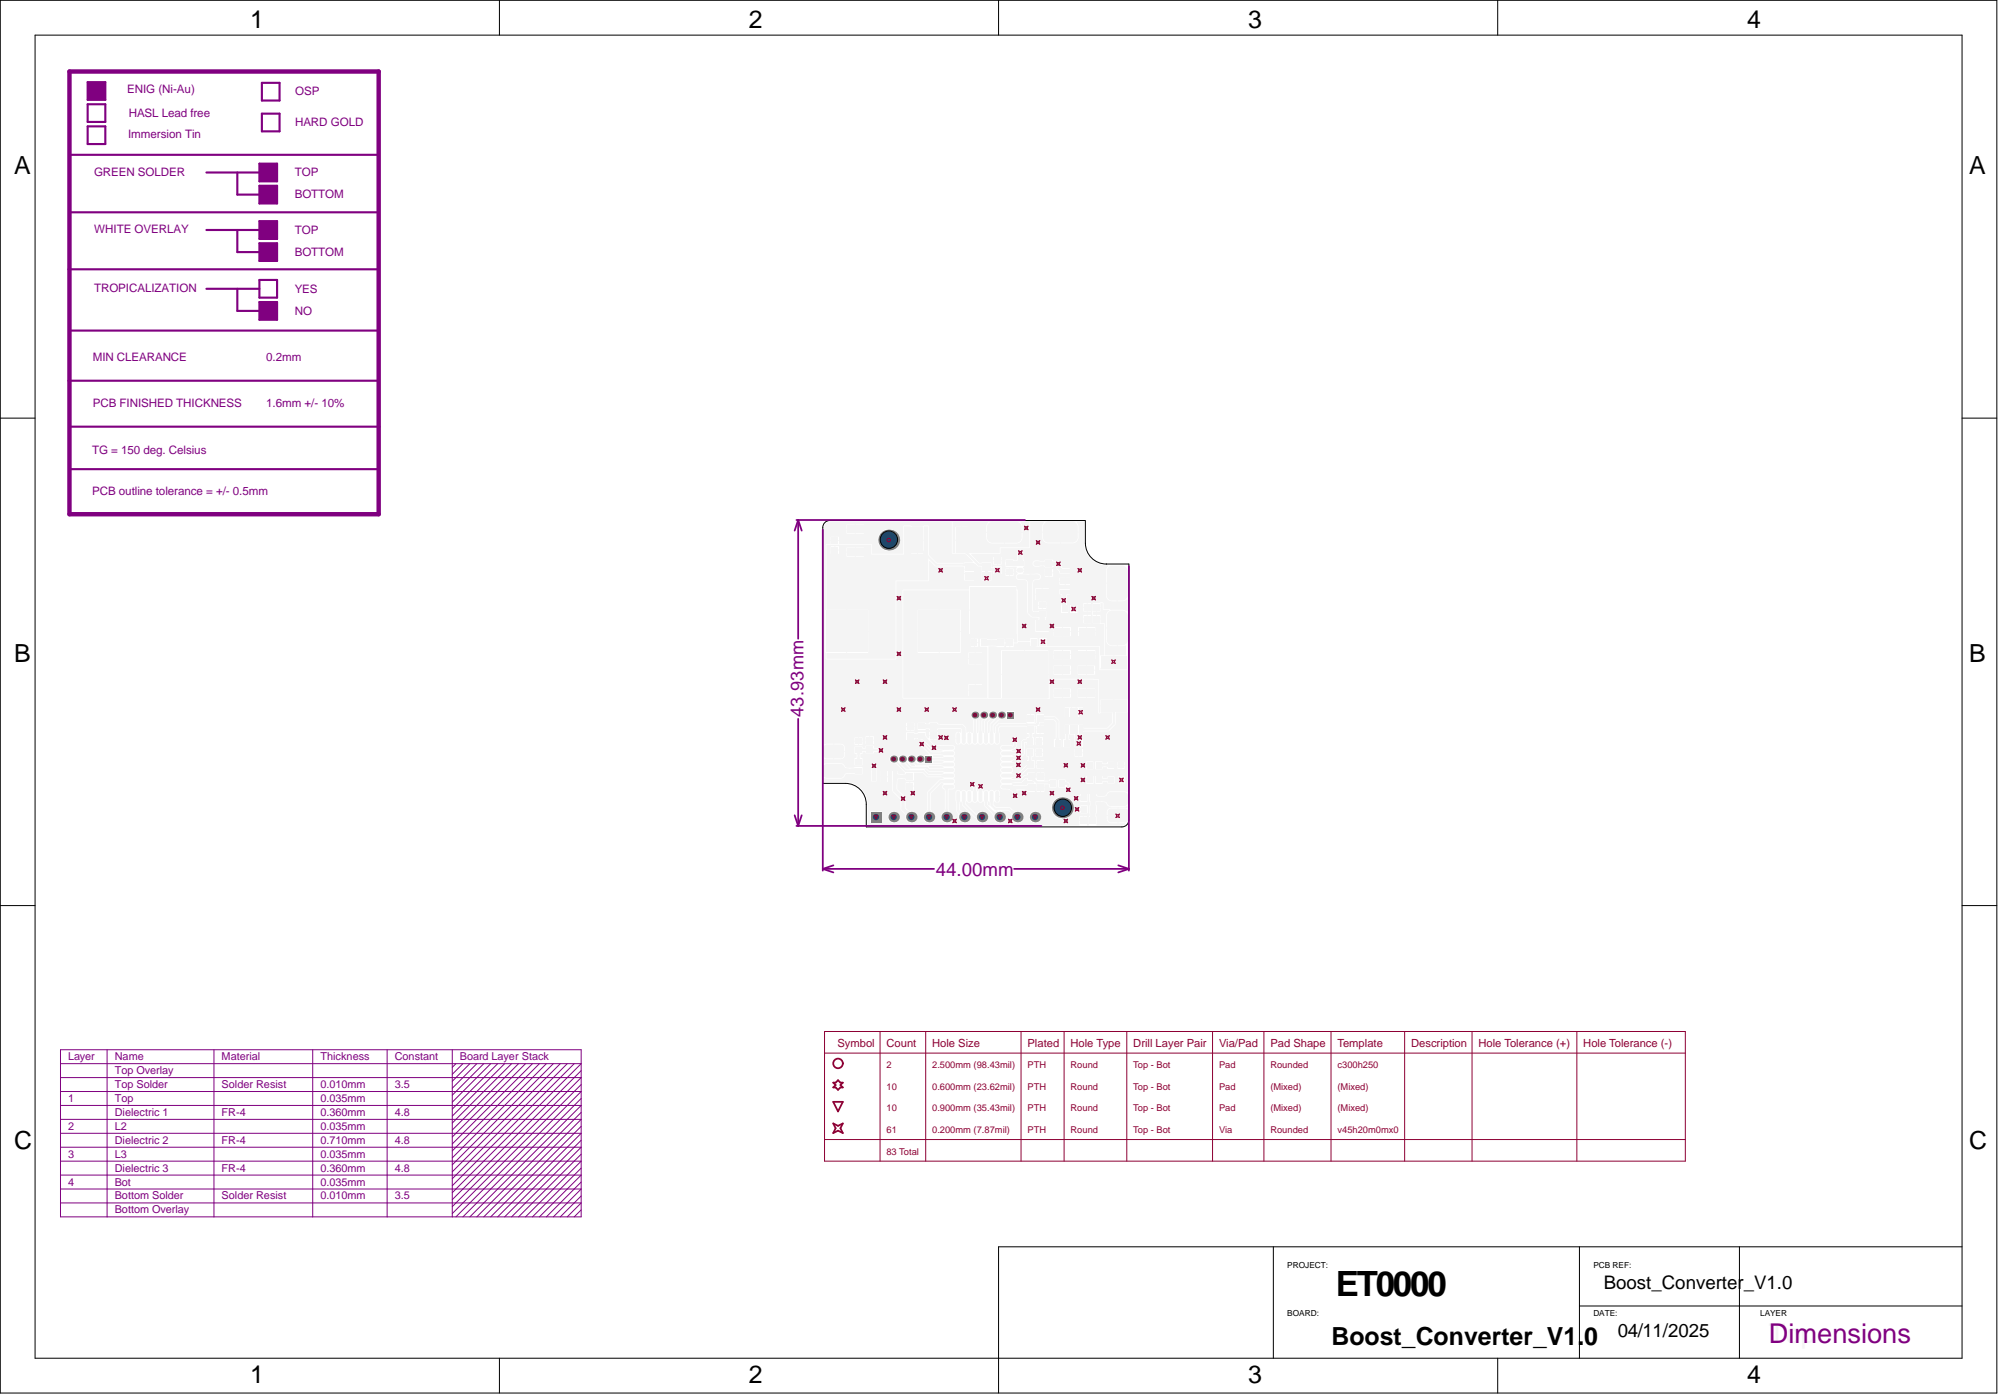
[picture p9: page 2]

Symbol | Count | Hole Size | Plated | Hole Type | Drill Layer Pair | Via/Pad | Pad Shape | Template | Description | Hole Tolerance (+) | Hole Tolerance (-)

Layer | Name | Material | Thickness | Constant | Board Layer Stack

2 10 10 61 | 2.500mm (98.43mil) 0.600mm (23.62mil) 0.900mm (35.43mil) 0.200mm (7.87mil) | PTH PTH | Round Round | Top - Bot Top - Bot | Pad Pad Pad Via | Rounded (Mixed) (Mixed) Rounded | c300h250 (Mixed) (Mixed) v45h20m0mx0

Top Overlay
Top Solder | Solder Resist | 0.010mm | 3.5

1 | Top | | 0.035mm

Dielectric 1 | FR-4 | 0.360mm | 4.8

Dielectric 2 | FR-4 | 0.710mm | 4.8

83 Total

Dielectric 3 | FR-4 | 0.360mm | 4.8

4 | Bot | | 0.035mm

Bottom Solder | Solder Resist | 0.010mm | 3.5
Bottom Overlay

PROJECT: ET0000 BOARD: Boost_Converter_V1.0 | PCB REF: Boost_Converter_V1.0

DATE: 04/11/2025 | LAYER Top Dimensions
